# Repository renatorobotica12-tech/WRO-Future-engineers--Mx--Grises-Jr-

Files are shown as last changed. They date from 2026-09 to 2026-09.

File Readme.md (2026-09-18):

<div align="center">

# 🏎️ LOS GRISES JR
## World Robot Olympiad 2026  
### Future Engineers Category
<p align="center">
  
</p>

<br>





<br>






<br>







<br>

---

# 📷 Final Competition Robot

**Insert final robot hero image here**

*(Recommended image: front three-quarter view showing the complete vehicle)*

---

### Official Engineering Repository

Documentation of Team Los Grises Jr's autonomous vehicle developed for:
**World Robot Olympiad 2026 — Future Engineers Category**

---

</div>

# 🚗 Project Overview

Our robot is a fully autonomous four-wheel vehicle designed for the **World Robot Olympiad 2026 Future Engineers competition**.

The objective of this project is to develop a reliable autonomous vehicle capable of navigating the competition environment through a combination of:

- Mechanical engineering.
- Embedded electronics.
- Autonomous control algorithms.
- Sensor processing.
- Software architecture.
- Iterative testing and optimization.

The final platform combines:

| System | Implementation |
|:---|:---|
| Steering | Ackermann steering geometry |
| Drive System | Rear-wheel drive |
| Main Controller | LEGO Mindstorms EV3 Brick, running ev3dev (Debian Linux) |
| Coprocessor | 1 Arduino Nano, multiplexing the five ultrasonic sensors |
| Vision System | HuskyLens AI Camera, through a LEGO UART adapter |
| Distance Measurement | Five ultrasonic sensors |
| Communication | USB serial at 115200 baud, plus LEGO UART for the camera |
| Electronics | Custom-designed PCB |
| Control Algorithm | Proportional wall-centring, with measured filtering and hold-over |
| Control Software | Python, modular package (`Src/ev3dev`) |

---

# ⚡ Quick System Overview

<div align="center">

```mermaid
flowchart TD
    HUSKY["📷 HuskyLens Camera"]
    ULTRA["📡 Ultrasonic Sensors ×5"]
    IMU["🧭 AbsoluteIMU"]

    OFDL["OFDL UART Adapter"]
    PCB["🔌 Custom PCB"]
    NANO["⚙️ Arduino Nano"]

    EV3["🧠 LEGO EV3<br/><i>running ev3dev</i>"]

    STEER["🔄 Steering Motor<br/>port A"]
    DRIVE["🚗 Drive Motor<br/>port B"]

    HUSKY --> OFDL
    ULTRA --> PCB
    PCB --> NANO

    OFDL -->|"LEGO UART · port 3"| EV3
    NANO -->|"USB serial · 115200 baud"| EV3
    IMU -->|"I²C · port 2"| EV3

    EV3 --> STEER
    EV3 --> DRIVE

    classDef sensor fill:#FFE0B2,stroke:#E65100,stroke-width:2px,color:#000
    classDef bridge fill:#B3E5FC,stroke:#01579B,stroke-width:2px,color:#000
    classDef brain  fill:#C8E6C9,stroke:#1B5E20,stroke-width:3px,color:#000
    classDef motor  fill:#F8BBD0,stroke:#880E4F,stroke-width:2px,color:#000

    class HUSKY,ULTRA,IMU sensor
    class OFDL,PCB,NANO bridge
    class EV3 brain
    class STEER,DRIVE motor
```

</div>

The robot uses a distributed architecture where each subsystem performs a specific role:

- The **Arduino Nano** measures the five ultrasonic sensors and streams them over USB.
- The **OFDL adapter** translates the HuskyLens output into the LEGO UART protocol, so the EV3 sees the camera as an ordinary sensor.
- The **EV3 Brick**, running ev3dev, performs navigation decisions and motion control in Python.
- The **Custom PCB** organizes power distribution and signal routing for the sensor array.

**Why USB instead of I²C.** The sensors originally reached the brick over
I²C on a sensor port. The EV3 does not have I²C hardware: it bit-bangs
the protocol in software and it runs at a few kHz. Moving the Nano to USB
at 115200 baud removed that bottleneck and freed a sensor port.

---

# 📑 Table of Contents

- [👥 Team](#-team)
- [🚗 Project Overview](#-project-overview)
- [⚡ Quick System Overview](#-quick-system-overview)
- [⭐ Engineering Highlights](#-engineering-highlights)
- [📊 Robot Specifications](#-robot-specifications)
- [📸 Vehicle Gallery](#-vehicle-gallery)
- [🔩 Components and Hardware](#-components-and-hardware)
- [🛠 Mechanical Design](#-mechanical-design)
- [⚡ Electronics](#-electronics)
- [🔌 Custom PCB](#-custom-pcb)
- [💻 Software Architecture](#-software-architecture)
- [📡 Ultrasonic Sensor Fusion](#-ultrasonic-sensor-fusion)
- [🎮 Wall-Centring Controller](#-wall-centring-controller)
- [👁 Camera Avoidance](#-camera-avoidance)
- [🎯 Automatic Steering Calibration](#-automatic-steering-calibration)
- [🧮 Corner Counting](#-corner-counting)
- [🧠 Engineering Decisions](#-engineering-decisions)
- [📈 Current Performance](#-current-performance)
- [📓 Engineering Journal](#-engineering-journal)
- [📂 Repository Structure](#-repository-structure)
- [🏁 Conclusion](#-conclusion)

---

<div align="center">

### 📚 Jump straight to the detail






</div>

---

# 👥 Team

## 📷 Team Photo

<p align="center">
Team Los Grises Jr
</p>

---

# 👨‍💻 Renato Medina
<p align="center">

</p>

## Team Captain

| Information | Details |
|:---|:---|
| Age | 14 |
| Role | Team Captain and Programmer |
| Main Areas | Software, Integration |

### Responsibilities

- 💻 Software Development
- 🤖 Autonomous Navigation Algorithms
- ⚙️ Mechanical Design
- 🔧 Robot Integration
- 🧠 System Architecture
- 📚 Technical Documentation

---

### About Renato

Renato serves as the **Team Captain** and leads the software architecture, autonomous navigation development, project documentation, and system integration of the robot.

His robotics journey began through the **OnStage TMR program**, where he developed a strong interest in autonomous systems, embedded programming, and engineering design.

Since then, he has focused on combining:

- Software development.
- Electronics.
- Mechanical design.
- Control systems.

to create reliable robotic platforms.

For the WRO 2026 season, his objective is to develop a highly reliable autonomous vehicle while expanding his knowledge of embedded systems, control theory, and robotic engineering.

---

# 👩‍🔧 Paulina

## Mechanical & Electronics Designer

| Information | Details |
|:---|:---|
| Role | Mechanical & Electronics Designer |
| Main Areas | Assembly, Electronics, Testing |

### Responsibilities

- 🔩 Mechanical Assembly
- ⚡ Electronics Integration
- 🔌 PCB Installation
- 🧪 Robot Testing
- 📐 Structural Optimization
- 🛠 Cable Organization

---

### About Paulina

Paulina is responsible for the robot's mechanical construction and electronic integration.

Her work focuses on:

- Structural assembly.
- Sensor installation.
- PCB integration.
- Mechanical validation.
- Hardware reliability.

Her contributions have been fundamental in transforming the initial prototype into a competition-ready autonomous vehicle with improved stability and maintainability.

📷 **Insert Paulina working on assembly image here**

---

# 🤝 Team Responsibilities

| Area | Renato | Paulina |
|:---|:---:|:---:|
| Mechanical Design | ✅ | ✅ |
| Robot Assembly | ✅ | ✅ |
| Electronics Integration | | ✅ |
| PCB Installation | ✅ | ✅ |
| Software Development | ✅ | |
| EV3 Programming | ✅ | |
| Arduino Programming | ✅ | |
| Documentation | ✅ | ✅ |
| Testing & Validation | ✅ | ✅ |

---

# ⭐ Engineering Philosophy

> [!IMPORTANT]
>
> The development of Los Grises Jr is based on continuous engineering improvement.
>
> Every subsystem has been tested, analyzed, modified, and optimized with three main objectives:
>
> - Increase reliability.
> - Improve repeatability.
> - Simplify maintenance.

---

# ⭐ Engineering Highlights

The current robot incorporates multiple engineering improvements developed specifically for the **WRO Future Engineers Challenge**.

| Feature | Implementation |
|:---|:---|
| Steering System | Ackermann steering geometry |
| Drive System | Rear-wheel drive |
| Sensors | Five ultrasonic sensors, with dropout filtering |
| Vision | HuskyLens AI camera, with hold-over and nearest-block selection |
| Coprocessor | 1 Arduino Nano streaming over USB |
| Electronics | Custom PCB |
| Communication | USB serial at 115200 baud |
| Steering Calibration | Automatic, measured against the mechanical stops |
| Control | Proportional, with every gain measured and recorded |
| Drive Control | Closed loop on the encoder, not raw power |
| Software | Modular Python package |
| Sensor Mounting | Custom 3D printed supports |
| Mechanical Design | Optimized weight distribution |

---

<div align="center">

# 📊 Robot Specifications

<div align="center">

| Specification | Value |
|:---|:---|
| Competition | WRO Future Engineers 2026 |
| Robot Type | Autonomous Vehicle |
| Dimensions | 24 × 23 × 18 cm |
| **Mass** | **861 g** |
| Maximum Allowed Size | 30 × 30 × 30 cm |
| Steering System | Ackermann Steering |
| Drive System | Rear-Wheel Drive |
| Chassis | LEGO Mindstorms EV3 |
| Main Controller | LEGO EV3 Brick running ev3dev |
| Coprocessor | Arduino Nano |
| Vision System | HuskyLens AI Camera |
| Distance Sensors | Five Ultrasonic Sensors |
| Gyroscope | mindsensors AbsoluteIMU |
| Communication Protocol | USB serial, 115200 baud |
| Custom Electronics | Custom PCB |
| Sensor Supports | 3D Printed |
| Programming Languages | Python (EV3) and Arduino C++ (Nano) |
| Control Loop Rate | ~30 Hz measured on track |

</div>

---

# 📸 Vehicle Gallery

The following images show the final competition vehicle from different perspectives.

These photographs demonstrate:

- Mechanical construction.
- Sensor placement.
- Electronics integration.
- Cable organization.
- Overall vehicle design.

<div align="center">

| Front View | Top View | Right Side |
|:---:|:---:|:---:|
|  |  |  |

| Left Side | Rear View | Bottom View |
|:---:|:---:|:---:|
|  |  |  |

</div>

> [!NOTE]
>
> A demostration video will be added after the final validation tests are completed.

---

# 🔩 Components and Hardware

The robot combines LEGO components with custom embedded electronics to create a modular and reliable autonomous platform.

Each component was selected according to:

- Reliability.
- Compatibility.
- Mechanical integration.
- Software requirements.
- Long-term maintainability.

| Component | Quantity | Function | Status |
|:---|:---:|:---|:---:|
| LEGO EV3 Brick | 1 | Main controller, runs ev3dev | ✅ |
| EV3 Medium Motor | 1 | Rear-wheel traction — **port B** | ✅ |
| EV3 Medium Motor | 1 | Ackermann steering — **port A** | ✅ |
| Ultrasonic Sensors | 5 | Distance measurement | ✅ |
| Arduino Nano | 1 | Sensor acquisition, USB serial | ✅ |
| HuskyLens AI Camera | 1 | Vision processing — **port 3** | ✅ |
| mindsensors AbsoluteIMU | 1 | Heading and corner counting — **port 2** | ✅ |
| OFDL UART Adapter | 1 | Presents the camera as a LEGO sensor | ✅ |
| Custom PCB | 1 | Power and signal distribution | ✅ |
| LEGO Wheels | 4 | Vehicle mobility | ✅ |
| 3D Printed Supports | Multiple | Sensor mounting | ✅ |

> [!NOTE]
> The complete port assignment, verified on the robot, is in
> [`mechanic/List of ports and components.md`](mechanic/List%20of%20ports%20and%20components.md).

---

# 🛠 Mechanical Design

## Design Evolution

The mechanical structure of the robot was developed through multiple iterations focused on:

- Structural rigidity.
- Weight distribution.
- Driving stability.
- Maintenance accessibility.
- Competition compliance.

Rather than modifying only a single prototype, the robot evolved progressively through testing and engineering improvements.

Every redesign addressed specific limitations discovered during previous experiments.

The result is a compact autonomous vehicle designed for reliability and repeatability.

---

## 📷 Mechanical Design Overview

<div align="center">

**Insert chassis evolution image here**

</div>

---

# 📏 Final Dimensions

| Measurement | Value |
|:---|:---:|
| Length | 24 cm |
| Width | 23 cm |
| Height | 18 cm |
| **Mass** | **861 g** |

The final design remains within the official WRO Future Engineers national competition limit of:

```
30 × 30 × 30 cm
```

### Why the mass is worth recording

861 g is not just a specification line. Combined with the drive motor's
running torque it sets the vehicle's dynamic limits:

| Derived quantity | Value |
|:---|---:|
| Weight | 8.45 N |
| Tractive force available | ≈ 2.86 N |
| Maximum acceleration | ≈ 3.32 m/s² |
| Friction coefficient required not to slip | μ ≥ 0.34 |

The full derivation is in
[**docs/Control_Model.md § 5**](docs/Control_Model.md).

The available internal space allows integration of:

- EV3 electronics.
- Arduino coprocessor.
- Custom PCB.
- Sensor wiring.
- Steering mechanism.

---

# ⚖️ Weight Distribution

Achieving a balanced center of gravity was one of the main mechanical objectives.

Instead of concentrating all components in one area, the mass was intentionally distributed throughout the chassis.

## Main Design Decisions

| Component | Position |
|:---|:---|
| EV3 Brick | Rear section |
| Drive Motor | Center area |
| Steering Motor | Above steering mechanism |
| Custom PCB | Near sensor assembly |
| Arduino Nano | Adjacent to PCB |

This configuration improves:

- Acceleration stability.
- Braking behavior.
- Cornering performance.
- Mechanical reliability.

---

# 🔄 Ackermann Steering System

The robot uses an Ackermann-inspired steering mechanism powered by an EV3 Medium Motor.

Unlike differential steering systems, Ackermann geometry allows the vehicle to follow more realistic turning trajectories by reducing tire slip.

## Steering Control Method

The steering motor is controlled using encoder positions instead of continuous rotation.

This provides:

✅ Repeatable steering angles  
✅ Faster response  
✅ Automatic steering centering  
✅ Reduced positioning error  

---

## Steering Protection

The software limits the maximum steering angle to prevent:

- Mechanical overtravel.
- Transmission stress.
- Unnecessary motor load.

---

# 🚗 Rear-Wheel Drive

The vehicle uses a rear-wheel-drive configuration powered by an EV3 Medium Motor.

This architecture was selected because it provides several advantages:

| Advantage | Result |
|:---|:---|
| Better weight transfer | Improved acceleration |
| Independent steering system | Less interference |
| Simpler drivetrain | Increased reliability |
| Easier maintenance | Faster repairs |

Separating propulsion and steering makes vehicle behavior more predictable during autonomous navigation.

---

# 📡 Sensor Mounts

All ultrasonic sensors are installed using custom-designed 3D printed brackets.

<div align="center">

📷 **Insert sensor mount image here**

</div>

The supports were designed to:

- Maintain precise alignment.
- Reduce vibration.
- Improve rigidity.
- Simplify installation.
- Guarantee repeatable sensor positioning.

Compared with direct LEGO mounting, the printed supports significantly improve measurement consistency.

---

# ⚡ Electronics

The robot combines LEGO electronics with custom embedded hardware to create a modular electrical architecture.

The system is divided into two main processing units:

| Controller | Responsibility |
|:---|:---|
| LEGO EV3 Brick | Navigation, decision making, motor control |
| Arduino Nano | Ultrasonic acquisition and serial streaming |
| OFDL adapter | Camera protocol translation (not programmed by the team) |

This distributed architecture provides:

- Reduced wiring complexity.
- Lower EV3 port usage.
- Easier debugging.
- Better scalability.

---

# 🔌 Electronic Architecture

<div align="center">

```mermaid
flowchart LR
    subgraph ACQ ["📡 Acquisition"]
        direction TB
        U1["Ultrasonic 1<br/>left 90°"]
        U2["Ultrasonic 2<br/>left 25°"]
        U3["Ultrasonic 3<br/>front"]
        U4["Ultrasonic 4<br/>right 25°"]
        U5["Ultrasonic 5<br/>right 90°"]
    end

    subgraph ROUTE ["🔌 Routing"]
        PCB["Custom PCB"]
        NANO["Arduino Nano<br/><i>trig / echo · 9 ms apart</i>"]
    end

    subgraph DEC ["🧠 Decision"]
        EV3["LEGO EV3<br/><i>ev3dev · Python</i>"]
    end

    subgraph ACT ["⚙️ Actuation"]
        MA["Steering · port A"]
        MB["Drive · port B"]
        MD["Nano power · port D"]
    end

    U1 & U2 & U3 & U4 & U5 --> PCB
    PCB --> NANO
    NANO -->|"USB · 115200 baud<br/>≈110 lines/s"| EV3
    EV3 --> MA
    EV3 --> MB
    EV3 -.->|"dc-motor · 100% duty"| MD
    MD -.->|"power"| NANO

    classDef s fill:#FFE0B2,stroke:#E65100,color:#000
    classDef r fill:#B3E5FC,stroke:#01579B,color:#000
    classDef d fill:#C8E6C9,stroke:#1B5E20,stroke-width:3px,color:#000
    classDef a fill:#F8BBD0,stroke:#880E4F,color:#000

    class U1,U2,U3,U4,U5 s
    class PCB,NANO r
    class EV3 d
    class MA,MB,MD a
```

</div>

The architecture separates:

- Sensor acquisition.
- Data communication.
- Decision making.
- Vehicle control.

This modular approach allows each subsystem to be tested independently.

---

# 🔌 Custom PCB

<p align="center">
Custom interface PCB built around the Arduino Nano
</p>

One of the most important improvements during development was the creation of a custom Printed Circuit Board.

During early testing, sensors were connected individually using loose wiring.

Although functional, this approach caused:

❌ Cable clutter  
❌ Difficult maintenance  
❌ Loose connections  
❌ Limited organization  

To solve these problems, a dedicated PCB was designed specifically for this robot.

---

## PCB Functions

The custom PCB provides:

| Function | Purpose |
|:---|:---|
| Power distribution | Organized electrical supply |
| Signal routing | Cleaner connections |
| Sensor interfaces | Easy sensor replacement |
| Arduino interface | Simplified communication |
| Cable management | Improved organization |

---

## PCB Advantages

Compared with individual wiring, the PCB provides:

✅ Cleaner internal organization  
✅ Faster assembly  
✅ Easier troubleshooting  
✅ Higher mechanical reliability  
✅ Reduced accidental disconnections  
✅ Better future expansion capability  

---

<div align="center">

Software Architecture • Sensor Fusion • Wall Centring • Camera Avoidance • Steering Calibration • Corner Counting • Engineering Decisions
</div>
# 💻 Software Architecture

The control software runs in Python on the EV3 brick under ev3dev. It is
organised as a package, `Src/ev3dev/wro`, where each module owns one part
of the robot and nothing else:

| Module | Responsibility |
|:---|:---|
| `config.py` | Every tunable value, and how each one was measured |
| `ultrasonics.py` | Reading the Nano, and filtering sensor dropouts |
| `husky.py` | The camera, and choosing which block to avoid |
| `imu.py` | Heading integration and corner counting |
| `robot.py` | Drive train and steering |
| `power.py` | Powering the Nano from a motor port |
| `ports.py`, `i2c.py`, `util.py` | Low-level helpers |

Two programs use that package, one per challenge:

| Program | Challenge |
|:---|:---|
| `open_ard.py` | Open challenge — three laps, walls only |
| `obs_ard.py` | Obstacle challenge — three laps, avoiding coloured pillars |

A third, `check_hw.py`, never races. It is a diagnostics tool with
thirteen commands, and it exists because several values cannot be decided
at a desk: which frame index belongs to which sensor, the gyroscope scale
and sign, and how far the steering actually travels. Guessing those wrong
produces failures that look like software bugs.

This organization improves:

✅ Code readability
✅ Debugging efficiency
✅ Testing capability
✅ Repeatability
✅ System reliability
✅ Ease of maintenance

## 🧩 Software Execution Flow

Every start-up runs the same three-stage sequence before the robot is
allowed to move:

```mermaid
flowchart TD
    A(["🏁 START"]) --> B["🔌 Power the Nano from port D<br/>open the serial link"]
    B --> C["🎯 Find both steering stops<br/>midpoint becomes centre"]
    C --> D["🧭 Calibrate gyroscope zero<br/><i>robot must be still</i>"]
    D --> E["📋 Print the values actually in use"]
    E --> F{{"⏸️ Wait for centre button"}}

    F --> G["📥 Read camera · ultrasonics · gyroscope"]
    G --> H{"Turn ≥ 87°<br/>and ≥ 1.5 s since<br/>the last corner?"}

    H -->|yes| I["➕ Count corner"]
    H -->|no| J
    I --> J{"12 corners<br/>reached?"}

    J -->|yes| K["🛬 Run on 500 ms<br/>still following walls"]
    K --> L(["🛑 STOP"])

    J -->|no| M["🚗 Drive at configured speed"]
    M --> N{"Camera sees<br/>a block?"}

    N -->|yes| O["👁 Steer around it<br/>by its colour"]
    N -->|no| P["📏 Centre between the walls"]

    O --> G
    P --> G

    classDef setup  fill:#E1BEE7,stroke:#4A148C,stroke-width:2px,color:#000
    classDef sense  fill:#FFE0B2,stroke:#E65100,stroke-width:2px,color:#000
    classDef choice fill:#FFF9C4,stroke:#F57F17,stroke-width:2px,color:#000
    classDef act    fill:#C8E6C9,stroke:#1B5E20,stroke-width:2px,color:#000
    classDef stop   fill:#FFCDD2,stroke:#B71C1C,stroke-width:3px,color:#000

    class B,C,D,E setup
    class G sense
    class H,J,N,F choice
    class I,M,O,P act
    class K,L stop
```

> [!NOTE]
> The order inside the loop is deliberate. The drive motor is given the
> speed computed on the **previous** iteration, so a corner detected on
> this iteration stops the robot without one last burst of throttle.

---
    
# 📡 Ultrasonic Sensor Fusion

The robot uses multiple ultrasonic sensors to determine its position relative to the surrounding walls.

Instead of relying on a single sensor, the readings are combined into two groups. Each group represents one side of the robot.

The lateral error is calculated as the difference between both groups:

```
left  = left_90  + left_25
right = right_25 + right_90

ERROR = -(left - right)
```

**The negation matters.** If the robot drifts towards the left wall, the
left readings fall, the error comes out **positive**, and a positive
steering command turns **right** — away from the wall. That sign is what
makes the whole chain close.

Because each side sums two sensors, a sideways drift moves all four at
once: two get closer while two get further away. The error therefore
grows about four times faster than the actual displacement, which is why
the gain looks small compared with the numbers involved.

## Handling dropped readings

When an ultrasonic sensor receives no echo, the firmware sends **125**
and clears that sensor's validity bit. **125 is a sentinel, not a
distance.** Added straight into the error, one dropout looks like an 80 cm
jump and slams the steering to full lock.

Measured with `check_hw.py lazo`: the error went from **+5 to −82 and
back to +31 in under a second, with the robot standing still.**

The fix is a three-state filter, applied per sensor:

| Situation | What is used |
|:---|:---|
| Valid reading | The reading itself, and it is remembered |
| Short dropout | The last good reading, held for 0.5 s |
| Long dropout | The maximum useful distance — there really is no wall |

A rolling median of three then removes isolated spikes that arrive with
their validity bit set.

Each run prints how many substitutions each sensor needed. That number is
a hardware health check: **a sensor substituting a quarter of the time is
a fault no amount of gain tuning compensates for.** Finding exactly that
is how we caught a dead sensor during testing.

# 🎮 Wall-Centring Controller

Steering correction is **proportional**:

```
angle = VOLANTE_KP × ERROR      clamped to ±VOLANTE_LIMITE
```

One gain, no derivative and no integral term. That is a deliberate
choice, not an omission — and the reasoning is recorded in
[`Logs_Tuning.md`](docs/Logs_Tuning.md), where the integral term was
found to saturate the steering actuator on track imperfections.

What makes this controller reliable is not the form of the equation but
knowing what the gain *means*:

| Gain | Saturates at error | Roughly |
|:---:|:---:|:---|
| 10 | 5 | 1 cm off centre — effectively on/off |
| 3 | 16.9 | 4 cm off centre |
| 1.5 | 33.7 | 8 cm off centre |

`config.py` derives that saturation point automatically, so the meaning
of the gain is visible next to the gain itself rather than having to be
recomputed by hand.

**One tuning lesson worth recording:** we once raised the gain as high as
10 chasing a robot that would not respond. The real cause was a dead
ultrasonic sensor pinning the error at a constant +62. With the sensor
repaired the true operating error turned out to be 5 to 9, and a gain of
10 saturated the steering permanently. **The gain was compensating for a
broken sensor.**

# ⚡ Speed Control

The two challenges use independent speeds, because they are solving
different problems:

| Challenge | Speed | Why |
|:---|:---:|:---|
| Open | 70 | Only has to stay centred; can afford to be quick |
| Obstacle | 40 | The camera must see a block, choose a side and complete the detour before reaching it |

Speed is commanded as a **percentage of the motor's maximum speed**, with
the EV3 regulating on the encoder. If a wheel is slowed by a track
imperfection, the controller raises power on its own until the commanded
speed is recovered. Commanding raw duty cycle instead is open loop: the
robot simply bogs down. We changed to closed loop after exactly that kept
happening on track.

# 👁 Camera Avoidance

In the obstacle challenge the camera takes over the steering whenever it
sees a coloured pillar. The rule is a proportional controller on the
block's **position in the image**:

```
error = X - target
angle = map(error, -160..+160, -limit..+limit)
```

`target` is where the block should end up in the frame, and it is the
knob that sets how wide the detour is:

| Colour | ID | Target | Result |
|:---|:---:|:---:|:---|
| Red | 1 | −150 | Block ends up left in frame → robot passes on the **right** |
| Green | 2 | +150 | Block ends up right in frame → robot passes on the **left** |

This reads backwards the first time. It is because the camera looks where
the robot is *going*, not at the block: to leave a pillar on your left,
you must be pointing to the right of it.

The target must stay inside ±160, the edge of the image. **A target
outside that range is a position the block can never reach**, so the
error never crosses zero and the steering never straightens out while the
block is in view.

## Three problems the camera created

**The adapter's documented data layout is wrong.** Its README lists six
values as `State, ID, X, Y, W, H`. The adapter actually returns **eight**
values in a different order: `X, Y, W, H, ID, State`. We found this by
watching index 5 alternate between 1 and 7 — exactly the codes for
"object detected" and "sees none" — with every other value dropping to
zero when it read 7.

**Reading it naively cost 49 ms.** Eight separate reads took long enough
to hold the whole control loop at 20 Hz. Reading the raw 32-byte block in
one atomic call takes 5 ms, and has the side benefit that data from two
frames can never be mixed.

**The camera flickers, and the adapter switches blocks.** A one-frame
dropout used to hand control back to wall following, which at that
instant saw a large error and went to full lock: measured at **+1.9° to
+50.6° and back inside 300 ms, with the block in view the whole time.**
And with two pillars visible, the adapter alternates which one it
reports, producing commands for opposite sides on consecutive loops.

Both are solved, but not the same way:

| Problem | Solution | Why this one |
|:---|:---|:---|
| Flicker | Hold the last good command for 0.15 s | Covers the 1–3 loop dropouts measured |
| Block switching | Only yield control to a **wider** block | Wider means closer; the closest pillar is the urgent one |

We first tried stretching the hold window to fix both. It did not work —
the retention rate tripled to 31 % while the switching continued
unchanged, because the adapter stays on the other block for longer than
any reasonable window. **The longer window only made the robot act on
stale images.** Width is the right criterion, and it is the only
proximity information the adapter provides.

# 🎯 Automatic Steering Calibration

At every start-up the robot pushes the steering against both mechanical
stops and takes the midpoint as zero. That is reliable even if the robot
was stored with the wheels turned.

Two things were learned building this:

**The stop is not where the motor stops moving.** At 40 % duty the
steering advances 28 degrees and jams halfway; it takes 100 % to actually
reach the stop. An earlier version accepted the first stall as the stop,
measured 26 degrees of travel instead of 111, and put the centre almost
50 degrees off. The search now walks the full power ladder every time.

**Forced travel and free travel are different numbers, and the
difference is not steering.** Measured on this robot: 153 degrees pushing
at full power, 119 at minimum power. Those 34 degrees are the mechanism
flexing against the stops. The steering limit is derived from the **free**
travel with a 15 % margin; taking it from the forced travel would make
the steering fight the stops on every correction.

# 🧮 Corner Counting

Laps are counted by integrating the gyroscope: 87 degrees of accumulated
turn is a corner, twelve corners is three laps.

That works in the open challenge. In the obstacle challenge it broke,
and the reason is worth recording: **while avoiding a block the steering
goes to full lock and the robot genuinely turns.** The gyroscope cannot
tell that from a track corner, accumulates its 87 degrees, and counts a
corner that does not exist.

Measured on track: **two corners 1.1 seconds apart, where the real ones
were arriving every 6.** In a race that is fatal — each false corner
brings the target of twelve closer, and the robot brakes mid-track
believing it has finished.

Corners arriving closer together than 1.5 seconds are now discarded. The
angle is still reset, because that turn physically happened and carrying
it forward would trigger the next corner early. Each run reports how many
false corners were rejected.

---

# 🧠 Engineering Decisions

Every major engineering decision was based on testing, analysis, and continuous improvement.

| Decision | Reason | Benefit |
|:---|:---|:---|
| Ackermann Steering | More realistic vehicle geometry | Smoother turns |
| Rear-Wheel Drive | Separates propulsion and steering | Better reliability |
| Encoder Steering | Absolute position control | Repeatable angles |
| Five Ultrasonic Sensors | Increased environmental awareness | Better perception |
| Arduino Nano Coprocessor | Dedicated sensor processing | Reduced EV3 workload |
| USB instead of I²C | The EV3's sensor-port I²C is bit-banged in software at a few kHz | Removed the bottleneck, freed a port |
| Custom PCB | Organized electronics | Improved maintenance |
| 3D Printed Mounts | Fixed sensor position | Better measurements |
| Python on ev3dev | Control maths written literally instead of approximated with blocks | Every gain carries its reasoning |
| Modular Software | Independent modules | Easier development |
| Proportional control | The integral term saturated the actuator on track imperfections | Predictable, tunable behaviour |
| Closed-loop drive | Raw duty cycle stalls against track imperfections | Speed is held, not just requested |
| Sensor dropout filter | A missing echo is a sentinel, not a distance | One dropout no longer causes full lock |
| Camera hold-over | One lost frame is not a lost block | No steering jerk mid-avoidance |
| Nearest-block selection | The adapter switches between visible pillars | No contradictory commands |
| False corner rejection | An avoidance turn looks identical to a corner | Lap count survives the obstacle run |

---

# 📈 Current Performance

Current testing demonstrates that the robot provides reliable autonomous behavior.

Achievements:

✅ Stable lane-centering  
✅ Smooth steering corrections  
✅ Automatic steering calibration  
✅ Consistent multi-run performance  
✅ Arduino-EV3 link with **zero bad frames** across full runs  
✅ Control loop sustained at **~30 Hz** on track  
✅ Improved electrical reliability after PCB integration  
✅ Strong mechanical structure for repeated testing  

Every run reports its own diagnostics: loop rate, corners counted, false
corners rejected, bad frames from the Nano, and per-sensor substitution
counts. Those numbers are how hardware faults get caught before they are
mistaken for tuning problems.

The current platform provides a reliable foundation for completing future competition objectives.

---

# 📓 Engineering Journal

The complete engineering process is documented in a dedicated engineering journal.

The journal includes:

- Mechanical iterations.
- Hardware modifications.
- Software development.
- Testing procedures.
- Engineering decisions.
- Performance analysis.

| Document | What it covers |
|:---|:---|
| 📓 [**Engineering Journal**](docs/Engineering%20Journal.md) | The development story, entry by entry — including the failures |
| 📊 [**Tuning Log**](docs/Logs_Tuning.md) | Controller tuning, iteration by iteration, with observed behaviour |
| 🧮 [**Mathematical Control Model**](docs/Control_Model.md) | Every equation and constant, derived and cross-checked against measurement |
| 🔧 [**Software Guide**](Src/ev3dev/README.md) | Installation, the calibration sequence, and how to run each challenge |
| 🔌 [**Ports and Components**](mechanic/List%20of%20ports%20and%20components.md) | The complete wiring, verified on the robot |

---

# 📂 Repository Structure

```text
.
├── Src
│   ├── ev3dev                    Control software, Python on the EV3
│   │   ├── check_hw.py           Diagnostics, 13 commands
│   │   ├── open_ard.py           Open challenge
│   │   ├── obs_ard.py            Obstacle challenge
│   │   └── wro/                  The library the programs import
│   │       ├── config.py         Every tunable value, and how it was measured
│   │       ├── robot.py          Drive train and steering
│   │       ├── imu.py            Gyroscope and corner counting
│   │       ├── ultrasonics.py    The Nano, and dropout filtering
│   │       ├── husky.py          Camera and block selection
│   │       ├── power.py          Powering the Nano from a motor port
│   │       ├── ports.py          Sensor port modes
│   │       ├── i2c.py            Raw I2C access
│   │       └── util.py           Numeric helpers
│   │
│   └── arduino_nano              Firmware for the ultrasonic hub
│       ├── ultrasonic_hub_serial.ino    in use — USB, 115200 baud
│       ├── ultrasonic_hub_packet.ino    I2C fallback, framed
│       └── ultrasonic_hub.ino           original, one byte per request
│
├── docs
│   ├── Engineering Journal.md
│   ├── Logs_Tuning.md            Controller tuning, iteration by iteration
│   ├── Control_Model.md          Every equation and constant, derived
│   ├── OPEN_ARD_EQUIVALENCIA.md
│   ├── PROTOCOLO_I2C_MULTIPLEXOR.md     The Nano's I2C frame format
│   └── BLOQUE_GIRO_ABSOLUTEIMU_EV3.md   Gyroscope integration
│
├── Electronics                   PCB design notes
├── mechanic                      Diagrams, port list, 3D printable parts
├── Photos                        Team and vehicle photographs
├── Videos                        Demonstration footage
│
├── LICENSE
└── Readme.md
```

> [!NOTE]
> `Src/ev3dev/wro` is a library. The programs import it, but nothing
> inside it is meant to be run on its own. Start with
> [`Src/ev3dev/README.md`](Src/ev3dev/README.md), which covers
> installation, the calibration sequence and how to run each challenge.

---

# 📅 Development Timeline

| Date | Milestone |
|:---|:---|
| 4 Jul 2026 | Initial PD controller prototype |
| 8 Jul 2026 | PCB manufacturing |
| 10 Jul 2026 | PCB assembly and testing |
| 13 Jul 2026 | First control software beta |
| 21 Jul 2026 | I²C communication completed |
| 27 Jul 2026 | Sensor multiplexer integrated, 3D printed mounts fitted |
| 28 Jul 2026 | Final robot assembly |
| 24 Aug 2026 | Faulty Arduino Nano diagnosed after four weeks |
| 28 Aug 2026 | Open challenge completed on track |
| 6 Sep 2026 | IMU integrated for corner counting |
| 12 Sep 2026 | Migration to Python on ev3dev; Nano moved from I²C to USB |
| 13 Sep 2026 | Steering travel measured; steering command defect found and fixed |
| 13 Sep 2026 | Dead ultrasonic sensor diagnosed and repaired |
| 14 Sep 2026 | Camera hold-over, nearest-block selection, false corner rejection |

---

# 🙏 Acknowledgements

We would like to thank our mentors, teachers, and everyone who supported the development of this project throughout the WRO 2026 season.

Their guidance, technical advice, and encouragement were essential in transforming an initial concept into a functional autonomous vehicle.

---

# 🏁 Conclusion

The current version of the **Los Grises Jr autonomous vehicle** represents the result of an iterative engineering process involving:

- Mechanical design.
- Electronics development.
- Embedded programming.
- Control theory.
- Autonomous navigation.

Compared with the earliest prototypes, the final platform incorporates:

✅ Custom-designed PCB  
✅ Arduino Nano coprocessor streaming over USB  
✅ Ackermann steering system  
✅ Automatic steering calibration, measured against the mechanical stops  
✅ Proportional wall-centring with measured, documented gains  
✅ Camera avoidance with hold-over and nearest-block selection  
✅ Modular Python software architecture  
✅ Improved mechanical reliability  

The project continues evolving toward the completion of the remaining WRO challenges while maintaining the engineering principles that guided the entire development process:

> **Reliability, repeatability, and continuous improvement.**

---

<div align="center">

# 🏎️ Team Los Grises Jr

## World Robot Olympiad 2026  
## Future Engineers Category

</div>

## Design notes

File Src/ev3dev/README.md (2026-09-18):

# Programa de Arath portado a ev3dev

Version en Python de los dos programas Arduino de Arath, corriendo sobre
el ladrillo EV3. No reemplaza a los programas EV3-G del proyecto `ev3/`;
es un camino paralelo.

## Por que ev3dev y no EV3-G

El programa de Arath es codigo, no bloques. En EV3-G hubo que aproximarlo
(ver `documentos/OPEN_ARD_EQUIVALENCIA.md`): el `map` y el factor 0.9 se
cambiaron por el bloque `PID_R_20`, la zona muerta se omitio y el conteo
de esquinas se rehizo con bloques. En ev3dev cada una de esas piezas se
escribe tal cual, y ademas se puede leer el Nano por USB en vez de por el
I2C lento de los puertos de sensores.

## Cableado

Confirmado en el robot con `check_hw.py puertos`:

| Puerto | Dispositivo | Como lo ve ev3dev |
|---|---|---|
| Sensor 2 | mindsensors AbsoluteIMU | `ms-absolute-imu` en `ev3-ports:in2:i2c17` |
| Sensor 3 | HuskyLens por el adaptador OFDL | `ev3-uart-84` |
| USB del ladrillo | Arduino Nano, cinco ultrasonicos | `/dev/ttyUSB0` |
| Motor A | volante | `lego-ev3-m-motor` |
| Motor B | traccion | `lego-ev3-m-motor` |

Los puertos de sensores 1 y 4 y los de motores C y D quedan libres.

Dos cosas no coinciden con `documentos/OPEN_ARD_EQUIVALENCIA.md`, que
describia el montaje de EV3-G:

- la traccion **no** es un motor grande en D, sino un **mediano en B**;
- el volante **no** esta en B sino en **A**.

Por eso `robot.py` usa la clase generica `Motor` y no `LargeMotor` ni
`MediumMotor`: esas dos filtran por `driver_name` y `LargeMotor` revienta
con un motor mediano. Nada de lo que hace ese archivo depende del tamano
del motor.

### El Nano por USB

Se le carga el firmware nuevo
[`arduino_nano/ultrasonic_hub_serial`](../arduino_nano/ultrasonic_hub_serial/ultrasonic_hub_serial.ino)
y se conecta con su propio cable USB al puerto USB del ladrillo. El
cableado de los ultrasonicos no cambia: mismos pines trig y echo.

Manda lineas ASCII a 115200 baudios:

```
U d1 d2 d3 d4 d5 mascara trama checksum
```

Una linea despues de **cada** sensor, no de cada barrido, para que el EV3
siempre tenga el dato mas fresco. Son unas 110 lineas por segundo. El EV3
descarta las viejas y se queda con la ultima completa.

Por que asi y no por I2C: el I2C de los puertos de sensores del EV3 no es
hardware, lo genera por software y va a pocos kHz. Ademas libera un
puerto de sensores y deja los pines A4 y A5 del Nano libres.

### La HuskyLens

El adaptador de OFDL Robotics no expone la camara por I2C: lleva un
Arduino Pro Mini que traduce los datos al **protocolo LEGO UART**. Para
el EV3 es un sensor LEGO cualquiera, asi que **ev3dev lo detecta solo**.
No hay que tocar el modo del puerto ni cargar drivers, a diferencia del
Nano en I2C.

**Ojo con el orden de los valores: el README del adaptador no coincide
con lo que entrega de verdad.** Ahi dice seis valores en el orden
`State, ID, X, Y, W, H`. Medido en el robot son **ocho** valores s32 y el
orden es otro:

```
0 X   1 Y   2 W   3 H   4 ID   5 State   6 y 7 siempre 0
```

Se confirma mirando el indice 5: alterna entre 1 y 7, que son justo los
codigos de "objeto detectado" y "no ve ninguno", y cuando vale 7 todos
los demas se van a cero.

`husky.py` lee `bin_data` en vez de ocho `value(i)`: es una sola lectura
atomica de 32 bytes, asi que no mezcla datos de dos fotogramas, y tarda
5 ms en vez de 49 ms. A 49 ms la camara sola dejaria el lazo en 20 Hz.

Codigos de State del adaptador:

| Codigo | Significado |
|---:|---|
| 9 | adaptador conectado pero HuskyLens no |
| 8 | conectada, sin objetos aprendidos |
| 7 | conectada y con objetos aprendidos, no ve ninguno |
| 1 | hay objeto detectado |
| 0 | puerto desconectado o perdida de datos |

`obs_ard.py` imprime este estado al arrancar, antes de calibrar.

## Estructura

Solo se corren tres archivos. La carpeta `wro/` es una biblioteca: los
programas la importan, pero **no se ejecuta nada de adentro**, igual que
los bloques `ARD` o `PID_R_20` de EV3-G existen para que los programas
los llamen y no para correrlos sueltos.

```
ev3dev/
  check_hw.py        SE CORRE  diagnostico; primero que nada
  open_ard.py        SE CORRE  prueba abierta, tres vueltas
  obs_ard.py         SE CORRE  prueba de obstaculos

  wro/               no se corre nada de aqui
    config.py        se EDITA: puertos, cableado y ganancias
    robot.py         traccion y volante
    imu.py           AbsoluteIMU e integracion del angulo
    ultrasonics.py   Nano, por USB o por I2C
    husky.py         HuskyLens por el adaptador OFDL
    ports.py         modos I2C de los puertos de sensores
    i2c.py           acceso I2C crudo
    util.py          map y constrain de Arduino
```

De esos tres, `check_hw.py` no mueve el robot salvo en el comando
`volante`: solo lee sensores e imprime. Es el que se usa para llenar
`wro/config.py`. Los otros dos son las carreras.

## Instalacion

En el ladrillo, con ev3dev ya arrancado:

```bash
sudo pip3 install pyserial smbus2
```

`smbus2` solo hace falta si dejan el Nano en I2C (`ARD_BACKEND = 'i2c'`).

Copiar la carpeta al ladrillo conservando el nombre, para que quede
`~/ev3dev/check_hw.py` y `~/ev3dev/wro/config.py`:

```bash
scp -r ev3dev robot@ev3dev.local:~/ev3dev
```

Dar permiso de ejecucion:

```bash
chmod +x ~/ev3dev/*.py
```

Todos los comandos de aqui en adelante se corren parados en esa carpeta:

```bash
cd ~/ev3dev
```

Los archivos deben conservar finales de linea LF. Si al correrlos sale
`bad interpreter`, es eso.

Si al abrir el puerto serie sale permiso denegado:

```bash
sudo usermod -a -G dialout robot
```

## Antes de la primera corrida

Hay varias cosas que solo se pueden medir en el robot. `check_hw.py` las
resuelve una por una.

```bash
python3 check_hw.py puertos
```

Lista puertos, drivers, buses I2C, puertos serie y motores. Confirma que
el AbsoluteIMU aparece como `ms-absolute-imu`, que la HuskyLens aparece
en el puerto 3 como sensor UART y que existe `/dev/ttyUSB0`.

```bash
python3 check_hw.py serie
```

Lineas crudas del Nano. Separa un problema de cable de uno de formato.

```bash
python3 check_hw.py ultra
```

Trama ya interpretada, en vivo.

```bash
python3 check_hw.py mapear
```

Averigua solo que indice es cada ultrasonico: toma una linea base con
todo despejado y despues pide acercar la mano a uno por uno. Al final
imprime `IDX_IZQ`, `IDX_FRONTAL` e `IDX_DER` listos para pegar. La mano
va a unos 10 cm, no pegada al sensor: demasiado cerca no hay eco y el
firmware devuelve 125, que confunde la medicion.

```bash
python3 check_hw.py husky
```

Imprime el driver, la lista de modos y los seis valores en vivo. Resuelve
tres cosas: que poner en `HUSKY_MODO` (ev3dev llama a los modos `MODE0`,
`MODE1`... porque no conoce este sensor), en que rango vienen X e Y para
ajustar `HUSKY_CENTRO_X` y `HUSKY_CENTRO_Y`, y que ID le toca a cada
color para `HUSKY_ID_A` y `HUSKY_ID_B`. Pongan un bloque de cada color
delante de la camara y anoten el ID.

```bash
python3 check_hw.py escala
```

Calcula `IMU_ESCALA`: integra la lectura cruda mientras usted gira el
robot noventa grados a mano. Si sale negativo, dejenlo negativo.

La magnitud ya esta resuelta sin mover nada: el driver reporta
`units = d/s` y `decimals = 1`, o sea que el entero crudo viene
multiplicado por diez, y por eso `IMU_ESCALA = 0.1`. No es el 0.001 de
EV3-G, donde el bloque oficial si entrega mili-grados/s. Lo que falta
confirmar con este comando es **el signo**.

```bash
python3 check_hw.py motores
```

Mueve 15 grados un motor a la vez, con aviso antes de cada uno, para
confirmar cual es la traccion y cual el volante. Levanten el robot o
ponganlo sobre un soporte.

```bash
python3 check_hw.py volante
```

Manda el volante a los dos topes logicos, para fijar `VOLANTE_SIGNO`.

## Correr

```bash
python3 open_ard.py
```

```bash
python3 obs_ard.py
```

Los dos: centran el volante, calibran el giroscopio con el robot inmovil,
esperan el boton central, corren las tres vueltas y frenan. El boton de
retroceso detiene todo en cualquier momento.

## Equivalencias con los programas de Arath

| Arduino / Mind+ | ev3dev |
|---|---|
| `mpu.prepararFacil` + `iniciar` + `calibrar(600)` | `Giroscopio.calibrar()` |
| `actualizar` + `zonaMuerta(0.3)` | `Giroscopio.actualizar()` |
| `angulo(Z)` / `reiniciarAngulos()` | `Giroscopio.grados` / `.reiniciar()` |
| cinco `readUltrasound` | `hub.actualizar()` |
| `map(((90i+25i)-(25d+90d))*-1, ...)` | `error_crudo()` por `VOLANTE_KP` |
| `Volante(error * 0.9)` | `Robot.girar_por_error()` |
| `Motor(velocidad)` | `Robot.avanzar()` |
| `millis()` | `time.time()` |
| `3 vueltas %n` | conteo de esquinas dentro del lazo de `obs_ard.py` |
| `actualizar Huskylens` | `HuskyLens.actualizar()` |
| `ERROR CAM = constrain(map(X+-100, ...))` | `HuskyLens.angulo_esquive()` |
| `huskylens.writeOSD` | telemetria por consola, `OBS_TELEMETRIA` |
| tira WS2812 segun esquinas | LEDs del ladrillo, `indicar_vuelta()` |

El esquive con camara se verifico numericamente: para todo X de 0 a 320 y
los dos IDs, `angulo_esquive()` da exactamente el mismo angulo que la
formula de Mind+, una vez trasladado el centro de 90 a 0.

## Diferencias deliberadas

**El factor 0.9.** En el original el error ya sale mapeado a 70..110 y
despues se multiplica por 0.9, lo que deja el rango en 63..99 y el centro
en 81, no en 90. Si el robot de Arath va recto con eso, ese 0.9 compensa
un desalineado mecanico del servo. Por eso se separo en `VOLANTE_KP`
(ganancia) y `VOLANTE_TRIM` (centro), que empieza en 0. Notese que el
camino de la camara **no** lleva ese 0.9, lo cual refuerza que era trim.

**Que bloque mira la camara.** Arath pide los dos primeros recuadros de
la HuskyLens y se queda con el mas ancho, y usa el indice del recuadro
como si fuera el color. El adaptador OFDL devuelve **un solo** recuadro
por lectura, pero devuelve su **ID aprendido de verdad**, que es mas
confiable que el indice. Lo que se pierde es el criterio de "el mas
ancho" cuando hay dos bloques a la vista a la vez. Hay que ver en pista
si el recuadro que entrega el adaptador es el mas grande o simplemente el
primero; `check_hw.py husky` con dos bloques delante lo resuelve en un
minuto.

**Llamadas repetidas.** El original llama a `actualizar Huskylens` tres
veces por vuelta de lazo y a `Actualizar Distancia` dos. Es ruido de
programacion por bloques; aqui se lee cada sensor una sola vez por vuelta.

**El sensor frontal.** Arath lo lee y no lo usa en ninguna decision. Aqui
se lee igual porque viene gratis en la misma trama, y queda en
`hub.frontal` para cuando haga falta.

## Lo que falta probar en pista

- Confirmar `IMU_ESCALA` y su signo.
- Confirmar los indices de los cinco ultrasonicos.
- Confirmar el ID de cada color en la HuskyLens.
- Medir cuantas vueltas de lazo por segundo salen de verdad. Los dos
  programas reportan al final cuantas tramas leyeron y cuantas salieron
  mal.
- Ajustar `VOLANTE_KP` y `HUSKY_DESPLAZAMIENTO_PX`: ese ultimo es cuanto
  se abre el rodeo alrededor del bloque.

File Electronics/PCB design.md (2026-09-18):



# PCB Design

This directory contains the hardware design files for the custom PCB used in the project.

The board is designed around an Arduino Nano and provides:
- Power input through a screw terminal.
- Regulated power distribution to multiple JST connectors.
- Dedicated input and output connectors for external peripherals.
- Optional I2C expansion header (EV3 compatible footprint).
- Enable (EN) control pads.
- Mounting holes for secure installation.
- Clearly labeled silkscreen for simplified assembly and debugging.

This PCB serves as the main interface board, simplifying wiring and providing a compact, reliable platform for connecting sensors, actuators, and expansion modules.

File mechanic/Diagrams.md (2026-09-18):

- FINAL PLATFORM diagram

| System | Implementation |
|:---|:---|
| Steering | Ackermann steering geometry |
| Drive System | Rear-wheel drive |
| Main Controller | LEGO Mindstorms EV3 Brick |
| Coprocessors | 2 Arduino Nano, 1 for the camera and one for the PCB |
| Vision System | HuskyLens AI Camera |
| Distance Measurement | Five ultrasonic sensors |
| Communication | I²C protocol and UART protocol |
| Electronics | Custom-designed PCB |
| Control Algorithm | Adaptive Dual PD Controller |
| Decision System | Finite State Machine |

---

- QUICK SYSTEM OVERVIEW diagram

                 ┌──────────────────┐               ┌────────────────┐
                 │ HuskyLens Camera │               │   Ultrasonic   │
                 └────────┬─────────┘               │  Sensors (x5)  │
                          │                         └───────┬────────┘
                          │ UART                            │
                          ▼                                 ▼
                 ┌──────────────────┐               ┌────────────────┐
                 │   Arduino Nano   │               │   Custom PCB   │
                 │      (UART)      │               └───────┬────────┘
                 └────────┬─────────┘                       │
                          │                                 ▼
                          │                         ┌────────────────┐
                          │                         │  Arduino Nano  │
                          │                         │     (I²C)      │
                          │                         └───────┬────────┘
                          │                                 │
                          └────────────────┬────────────────┘
                                           │
                                           ▼
                                   ┌────────────────┐
                                   │    LEGO EV3    │
                                   │   Controller   │
                                   └────────┬───────┘
                                            │
                            ┌───────────────┴───────────────┐
                            ▼                               ▼
                    ┌──────────────┐                ┌──────────────┐
                    │Steering Motor│                │  Drive Motor │
                    └──────────────┘                └──────────────┘

---

- TEAM RESPONSABILITIES diagram

| Area | Renato | Paulina |
|:---|:---:|:---:|
| Mechanical Design | ✅ | ✅ |
| Robot Assembly | ✅ | ✅ |
| Electronics Integration | | ✅ |
| PCB Installation | ✅ | ✅ |
| Software Development | ✅ | |
| EV3 Programming | ✅ | |
| Arduino Programming | ✅ | |
| Documentation | ✅ | ✅ |
| Testing & Validation | ✅ | ✅ |

---

- ENGINEERING HIGHLIGHTS diagram

| Feature | Implementation |
|:---|:---|
| Steering System | Ackermann steering geometry |
| Drive System | Rear-wheel drive |
| Sensors | Five ultrasonic sensors |
| Vision | HuskyLens AI camera |
| Coprocessors | 2 Arduino Nano, 1 for camera and 1 for pcb |
| Electronics | Custom PCB |
| Communication | I²C architecture |
| Steering Calibration | Automatic encoder-based calibration |
| Control | Adaptive Dual PD controller |
| Navigation | Finite State Machine |
| Software | Modular architecture |
| Sensor Mounting | Custom 3D printed supports |
| Mechanical Design | Optimized weight distribution |

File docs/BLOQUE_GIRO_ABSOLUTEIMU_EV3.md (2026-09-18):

# Bloque de giro para mindsensors AbsoluteIMU-ACG y EV3

El proyecto `ev3/WRO 26 I2C MULTI IMU.ev3` contiene el bloque personalizado **IMU_ANGULO**. Este bloque convierte la velocidad angular del eje Z en:

- **Z corregida:** velocidad de giro en grados por segundo.
- **GRADOS:** giro acumulado con signo; no se limita a 0–360.
- **VUELTAS:** giro acumulado dividido entre 360.

## Conexión recomendada

Monte el AbsoluteIMU plano y firme, con el eje Z perpendicular al piso. Conecte el sensor directamente a un puerto de sensores EV3 (1–4); no lo conecte al multiplexor de ultrasonidos.

En EV3-G, use el bloque oficial **Mindsensors-ABSIMU**, modo **Read Gyro**, y conecte su salida **Z Gyro** a la entrada **Z del sensor** de `IMU_ANGULO`.

Los datos del bloque oficial están en mili-grados por segundo. Por ello:

- **ESCALA = 0.001** con el bloque oficial Mindsensors-ABSIMU.
- **ESCALA = 1** si la lectura que entra ya está en grados por segundo, por ejemplo con el bloque Dexter corregido incluido en esta carpeta.
- **TIMER = 8** de forma predeterminada. No use el temporizador 8 en otra parte del programa mientras esté contando el giro.

## Uso

1. Deje inmóvil el robot al iniciar.
2. Lea varias veces `Z Gyro` durante uno o dos segundos y calcule el promedio. Escriba ese promedio en **OFFSET**. Si en reposo entrega aproximadamente cero, empiece con `OFFSET = 0`.
3. Antes de empezar el recorrido, llame una vez a `IMU_ANGULO` con **REINICIAR = verdadero**. Esta llamada pone GRADOS y VUELTAS en cero y prepara el temporizador.
4. Dentro del bucle principal, lea primero **Z Gyro** y después llame a `IMU_ANGULO` con **REINICIAR = falso**.
5. Use **GRADOS** para giros como 90°, 180° o 720°. Use **VUELTAS** si resulta más cómodo: 1 vuelta = 360°, 2.5 vueltas = 900°.

No agregue un bloque de espera largo dentro de este lazo. El bloque mide el tiempo real transcurrido con el temporizador EV3, de modo que sigue contando aunque el periodo del lazo varíe.

## Sentido del giro

El signo depende de la orientación física del sensor. Si al girar a la derecha los grados disminuyen y desea que aumenten, cambie **ESCALA** a `-0.001` (bloque oficial) o `-1` (lectura ya expresada en grados/s).

## Precisión para WRO

El giroscopio acumula cualquier pequeño error de offset. Calibre con el robot totalmente quieto, evite vibraciones y reinicie el contador justo antes de cada maniobra o tramo. Para giros cortos y repetibles conviene frenar unos grados antes del objetivo y terminar a menor velocidad.

La brújula del AbsoluteIMU puede ayudar a corregir deriva a largo plazo, pero cerca de motores, cables de potencia y estructuras metálicas suele sufrir interferencias; para contar vueltas completas el acumulador del giroscopio es la opción principal.

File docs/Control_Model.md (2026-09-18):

# 🧮 Mathematical Control Model

<div align="center">

**Los Grises Jr — WRO 2026 Future Engineers**

*Sensor fusion · Error · Control law · Kinematics · Torque · Steering geometry*

Every constant here is traceable either to a measurement on the robot or
to a line in [`Src/ev3dev/wro/config.py`](../Src/ev3dev/wro/config.py).
Where a value is an estimate rather than a measurement, it says so.

</div>

---

## 🚗 1. Vehicle Parameters

| Parameter | Symbol | Value |
|:---|:---:|---:|
| Mass | $m$ | **861 g** = 0.861 kg |
| Overall dimensions | — | 24 × 23 × 18 cm |
| Wheel diameter | $D$ | 56.0 mm |
| Wheel radius | $r$ | 28.0 mm = 0.028 m |
| Wheel circumference | $C$ | 175.93 mm |
| Wheelbase | $L_b$ | 24.0 cm |
| Track width | $W_t$ | 18.0 cm |
| Motor encoder resolution | — | 1° |
| Drive motor | — | EV3 Medium, port B |
| Steering motor | — | EV3 Medium, port A |

$$C = \pi D = \pi \times 56.0 = 175.93\ \text{mm}$$

---

## 📐 2. Wall-Centring Geometry

### 2.1 Sensor layout

Four lateral ultrasonic sensors, two per side: one perpendicular to the
chassis (90°) and one angled. A fifth sensor faces forward and is read
but not used in any control decision.

Let the corridor width be $W = 100\ \text{cm}$ and let $d$ be the lateral
displacement from the centre line, positive towards the left wall.

The perpendicular sensors measure:

$$r_{90}^{L} = \frac{W}{2} - d \qquad r_{90}^{R} = \frac{W}{2} + d$$

The angled sensors are mounted at **25° from perpendicular**. Their range
is therefore the perpendicular distance divided by $\cos 25°$:

$$r_{25} = \frac{1}{\cos 25°}\cdot r_{90} = 1.103\,r_{90}$$

### 2.2 The error signal

Each side is summed, and the error is the negated difference between
sides:

$$e = -\Big[(r_{90}^{L} + r_{25}^{L}) - (r_{25}^{R} + r_{90}^{R})\Big]$$

$$e = -\Big[(1 + 1.103)\left(\tfrac{W}{2} - d\right) - (1 + 1.103)\left(\tfrac{W}{2} + d\right)\Big]$$

$$\boxed{\;e = 2\,(1 + 1.103)\,d = 4.21\,d\;}$$

**The error is 4.21 times the physical displacement.** All four sensors
move at once — two approach the wall while two recede — so their
contributions add rather than cancel. This is why the error grows several
times faster than the displacement, and why the proportional gain looks
small next to the numbers involved.

> [!IMPORTANT]
> **Verification.** The model predicts $e = 42$ for a 10 cm displacement.
> Measured on track, a 10 cm displacement produces an error of
> approximately 40 — within 5 %, consistent with sensor tolerance.

### 2.3 Why the negation matters

If the robot drifts towards the **left** wall, $d > 0$, the left readings
fall, and $e$ comes out **positive**. A positive steering command turns
**right**, away from the wall.

The sign is what closes the loop. Without the negation the robot would
steer into the wall it is already approaching.

### 2.4 Decomposing a diagonal reading

A diagonal sensor's range splits into lateral and forward components:

$$Y_{\text{wall}} = D_{\text{diag}}\cos 25° = 0.906\,D_{\text{diag}}
\qquad
X_{\text{forward}} = D_{\text{diag}}\sin 25° = 0.423\,D_{\text{diag}}$$

This is what makes the angled sensors useful: the forward component means
they see a corner slightly before the perpendicular pair does.

---

## 🎮 3. The Wall-Centring Controller

### 3.1 Control law

$$\delta = \mathrm{clamp}\big(K_p \cdot e,\; -L_{\text{izq}},\; +L_{\text{der}}\big)$$

where $\delta$ is the steering angle in motor degrees relative to centre.

**There is no derivative or integral term.** That is a measured decision,
not an omission. The tuning log in [`Logs_Tuning.md`](Logs_Tuning.md)
records the integral term saturating the steering actuator on track
imperfections — corners generate a sustained error for a short period,
the integral accumulates it, and the steering deviates from its
geometric response.

### 3.2 Saturation: what the gain actually means

A proportional controller is only meaningful up to the point where it
saturates:

$$e_{\text{sat}} = \frac{L}{K_p}
\qquad\qquad
d_{\text{sat}} = \frac{e_{\text{sat}}}{4.21} = \frac{L}{4.21\,K_p}$$

With the measured limit $L = 50.6°$:

| $K_p$ | $e_{\text{sat}}$ | $d_{\text{sat}}$ | Character |
|:---:|:---:|:---:|:---|
| 10 | 5.1 | **1.2 cm** | Effectively bang-bang |
| 3 | 16.9 | **4.0 cm** | Narrow proportional band |
| 1.5 | 33.7 | **8.0 cm** | Wide proportional band |
| 0.47 | 107 | — | Never saturates in a 1 m corridor |

`config.py` computes $e_{\text{sat}}$ automatically as
`VOLANTE_ERROR_TOPE`, so the meaning of a gain sits next to the gain.

> [!CAUTION]
> **A gain can silently compensate for broken hardware.** We ran
> $K_p = 10$ while one ultrasonic sensor was dead. With its readings
> substituted by the filter, the error sat at a constant $+62$ — nearly
> four times the saturation point — and the steering was pinned at full
> lock regardless of the walls. After repair the true operating error was
> 5 to 9, and $K_p = 10$ saturated permanently. **The gain had been
> masking the fault.**

### 3.3 Speed and correction distance

At loop rate $f$ and forward speed $v$, the robot travels

$$\Delta s = \frac{v}{f}$$

between consecutive steering updates. At the measured
$f \approx 30\ \text{Hz}$, each correction covers 33 ms of travel.
Raising $v$ without raising $f$ increases $\Delta s$, which is why a
faster robot needs more gain for the same correction to arrive in time —
and why, past a point, weaving is a symptom of the loop rate rather than
of the gain.

---

## ⚙️ 4. Motor Kinematics and Linear Displacement

### 4.1 Distance from motor angle

$$d = \frac{\theta}{360°}\cdot C$$

$$\frac{C}{360} = \frac{175.93}{360} = 0.4887\ \text{mm/degree}$$

$$\theta = \frac{d}{0.4887}$$

The encoder resolves 1°, so the theoretical position quantum is
**0.49 mm** of wheel travel. That is the floor on odometric precision
before slip is considered.

### 4.2 Speed command to linear velocity

Speed is commanded as a percentage of the motor maximum:

$$\omega_{\text{cmd}} = \frac{v_{\%}}{100}\,\omega_{\max},
\qquad \omega_{\max} = 1560\ °/\text{s}$$

Converting to linear wheel speed:

$$v = \frac{\omega_{\text{cmd}}}{360}\cdot C$$

| $v_\%$ | $\omega_{\text{cmd}}$ | $v$ at the wheel |
|---:|---:|---:|
| 40 | 624 °/s | 0.305 m/s |
| 50 | 780 °/s | 0.381 m/s |
| 70 | 1092 °/s | 0.534 m/s |
| 100 | 1560 °/s | 0.763 m/s |

> [!NOTE]
> These assume direct drive from motor to wheel. Any gear reduction
> scales them down proportionally, and should be measured rather than
> assumed.

---

## 🔩 5. Torque, Traction and Acceleration

### 5.1 Available force

The EV3 Medium Motor has a reference running torque of
$\tau = 8\ \text{N·cm} = 0.08\ \text{N·m}$ and a stall torque of
$0.12\ \text{N·m}$. Stall torque is a blocked-rotor figure, not a driving
condition.

$$F = \frac{\tau}{r} = \frac{0.08}{0.028} \approx 2.86\ \text{N}$$

### 5.2 What the mass makes of it

With $m = 0.861\ \text{kg}$:

$$a_{\max} = \frac{F}{m} = \frac{2.86}{0.861} \approx 3.32\ \text{m/s}^2$$

$$W = mg = 0.861 \times 9.81 \approx 8.45\ \text{N}$$

### 5.3 The slip condition

Tractive force cannot exceed what friction can transmit:

$$F \le \mu\,N$$

Taking the full weight on the driven axle as an upper bound:

$$\mu_{\text{required}} \ge \frac{F}{W} = \frac{2.86}{8.45} \approx 0.34$$

Rubber on a smooth competition surface typically gives $\mu$ well above
0.34, so the robot should be **torque-limited rather than
traction-limited** under normal acceleration.

> [!IMPORTANT]
> The rear-wheel-drive layout puts only part of the mass on the driven
> axle, which raises the effective $\mu$ required. This was observed at
> the highest speeds tested, where the chassis began to drift on rear-tyre
> slip — the ideal kinematic model stops being accurate there.

### 5.4 Time to reach speed

$$t = \frac{v}{a_{\max}}$$

| Target | $v$ | $t$ (ideal) |
|---:|---:|---:|
| $v_\% = 40$ | 0.305 m/s | 0.09 s |
| $v_\% = 70$ | 0.534 m/s | 0.16 s |

These are upper-bound figures: they ignore drivetrain losses, rolling
resistance and the motor's own speed-torque curve, all of which reduce
available torque as speed rises.

---

## 🔄 6. Steering Geometry

### 6.1 Ackermann condition

With wheelbase $L_b$ and track width $W_t$, for a commanded steering
angle $\alpha$ the inner and outer wheels must take different angles to
share a turning centre:

$$\delta_{\text{inner}} = \arctan\!\left(\frac{L_b}{\dfrac{L_b}{\tan\alpha} - \dfrac{W_t}{2}}\right)
\qquad
\delta_{\text{outer}} = \arctan\!\left(\frac{L_b}{\dfrac{L_b}{\tan\alpha} + \dfrac{W_t}{2}}\right)$$

The turning radius measured to the centre of the rear axle is

$$R = \frac{L_b}{\tan\alpha}$$

With $L_b = 24.0\ \text{cm}$ and $W_t = 18.0\ \text{cm}$:

| $\alpha$ | $R$ | $\delta_{\text{inner}}$ | $\delta_{\text{outer}}$ |
|---:|---:|---:|---:|
| 10° | 136 cm | 10.7° | 9.4° |
| 20° | 66 cm | 22.0° | 18.4° |
| 30° | 42 cm | 34.0° | 26.9° |

Satisfying this geometry is what stops the inner wheel from scrubbing
through a turn.

> [!WARNING]
> **Open item: $L_b$ and $W_t$ need re-measuring.** The values above,
> 24.0 cm and 18.0 cm, are identical to the robot's overall **length** and
> **height** from the specification table (24 × 23 × 18 cm). Wheelbase is
> measured axle to axle and is necessarily shorter than the vehicle;
> track width is measured between wheel centres. These figures appear to
> have been taken from the bounding box rather than from the chassis.

### 6.2 Steering travel measurement

The steering is driven against both mechanical stops. Two distinct
quantities result:

| Quantity | Measured | Meaning |
|:---|---:|:---|
| $T_{\text{forced}}$ | $153°$ | Stop to stop at 100 % duty |
| $T_{\text{free}}$ | $119°$ | Reached at minimum duty |

The difference of $34°$ is **not steering**. It is the mechanism flexing
against the stops under load; it does not become wheel angle.

### 6.3 Deriving the limit

$$L = \frac{T_{\text{free}}}{2}\times 0.85 = \frac{119}{2}\times 0.85 = 50.6°$$

The factor 0.85 leaves a 15 % margin so the steering does not strike its
stops on every correction. Taking the limit from $T_{\text{forced}}$
would give $65°$, and the steering would spend the race fighting its own
end stops.

### 6.4 Centre and per-side limits

$$c = \frac{p_{+} + p_{-}}{2}$$

the midpoint of the two forced extremes. The forced travel is used
because both ends are reached the same way; the free ends are reached one
from centre and one from a stop, and are therefore not symmetric.

$$L_{\text{der}} = L\,f_{\text{der}} \qquad L_{\text{izq}} = L\,f_{\text{izq}}
\qquad f \in [0,1]$$

Expressing the clamp as a fraction keeps $L$ as the mechanical ceiling and
the fractions as the tuning knob, so re-measuring the mechanism rescales
both sides automatically.

---

## 👁 7. Camera Avoidance

### 7.1 Image coordinates

The HuskyLens reports a bounding box in a $320\times 240$ image. The
horizontal coordinate is re-centred:

$$X = X_{\text{raw}} - 160 \qquad X \in [-160,\,+160]$$

### 7.2 Control law

$$\delta_{\text{cam}} = \mathrm{clamp}\!\left(\frac{L}{160}\,(X - X_{\text{target}}),\;\text{lo},\;\text{hi}\right)$$

The gain is fixed by geometry, not tuned:

$$\frac{L}{160} = \frac{50.6}{160} = 0.316\ \text{degrees per pixel}$$

| Colour | ID | $X_{\text{target}}$ | Block ends up | Robot passes |
|:---|:---:|:---:|:---|:---|
| Red | 1 | $-150$ | Left of frame | **Right** of the pillar |
| Green | 2 | $+150$ | Right of frame | **Left** of the pillar |

The inversion is not a sign error. The camera looks where the robot is
**going**: to leave a pillar on your left, you must point to the right of
it.

### 7.3 Why the target must lie inside ±160

For the controller to converge there must exist a reachable $X$ with
$\delta_{\text{cam}} = 0$, which requires

$$\boxed{\;|X_{\text{target}}| \le 160\;}$$

If $X_{\text{target}} = 180$, then even at the extreme $X = 160$:

$$\delta_{\text{cam}} = 0.316\,(160-180) = -6.3°$$

The steering never straightens while the block is in view. At
$X_{\text{target}} = 150$ the proportional band covers
$X \in [-10,\,150]$ and the loop closes at $X = 150$.

### 7.4 Measured convergence

| $X$ | $\delta_{\text{cam}}$ |
|---:|---:|
| $+116$ | $-7.6$ |
| $+127$ | $-4.1$ |
| $+133$ | $-2.2$ |
| $+139$ | $-0.3$ |
| $+143$ | $+0.9$ |

$X$ climbs monotonically to the target, $\delta$ shrinks to zero and
crosses sign. The loop closes as predicted.

---

## 📡 8. Sensor Dropout Filtering

### 8.1 The sentinel problem

With no echo, the firmware reports $125$ and clears the sensor's validity
bit. **125 is a sentinel, not a distance.** Treated as one, a dropout
changes that side's sum by

$$\Delta = 125 - r_{\text{actual}}$$

With a typical $r_{\text{actual}} \approx 20\ \text{cm}$ that is
$\Delta \approx 105$, over six times $e_{\text{sat}}$ at $K_p = 3$.

**Measured with the robot standing still:** the error swung from $+5$ to
$-82$ and back to $+31$ in under one second.

### 8.2 The three-state filter

$$
r_{\text{used}} =
\begin{cases}
r & \text{valid, and } r < 125 \\[4pt]
r_{\text{last good}} & t - t_g \le T_{\text{hold}} \\[4pt]
r_{\max} & t - t_g > T_{\text{hold}}
\end{cases}
$$

with $T_{\text{hold}} = 0.5\ \text{s}$ and $r_{\max} = 100\ \text{cm}$,
followed by a rolling median of three.

### 8.3 Substitution rate as a health metric

$$\rho_i = \frac{n_{\text{sub},i}}{n_{\text{frames}}}$$

Measured: $\rho \approx 0$ for healthy sensors, $\rho = 0.25$ to $0.34$
for a faulty one. **A sensor above a few percent is a hardware fault**,
and no gain compensates for a quarter of its readings being fabricated.

---

## 🧭 9. Heading and Corner Counting

### 9.1 Integration

$$\theta_k = \theta_{k-1} + \omega_k\,\Delta t_k,
\qquad \omega_k = (\text{raw}_k - \bar b)\,s$$

$\Delta t_k$ is the **measured** elapsed time, not the nominal loop
period, so a varying loop rate introduces no bias.

### 9.2 The scale factor

$$s = 0.1$$

Exact by construction: the `ms-absolute-imu` driver in GYRO mode reports
`units = d/s` with `decimals = 1`, so the raw integer is ten times the
value in degrees per second.

**Independent check.** Integrating one full manual rotation gave
$s = 0.09795$, within 2 %. The exact value is kept; the measurement
confirmed the axis and the sign.

### 9.3 Bias calibration

$$\bar b = \frac{1}{N}\sum_{k=1}^{N}\text{raw}_k, \qquad N = 600$$

Averaging reduces the bias uncertainty by $\sqrt N = 24.5$. This matters
because bias error **integrates**: a residual $\varepsilon$ produces
drift $\varepsilon t$, growing without bound over a three-lap run.

### 9.4 Dead band

$$\omega_{\text{used}} =
\begin{cases} 0 & |\omega| < 0.3\ °/\text{s}\\ \omega & \text{otherwise}\end{cases}$$

Any residual bias below $0.3\ °/\text{s}$ contributes exactly zero while
driving straight, **bounding** drift rather than merely reducing it.

### 9.5 Corner detection

$$|\theta| \ge 87° \quad\text{and}\quad t - t_{\text{last}} \ge 1.5\ \text{s}$$

**87° rather than 90°** absorbs the small undershoot from the dead band
and from discrete integration.

**The 1.5 s interval** exists because the gyroscope cannot distinguish a
track corner from an avoidance manoeuvre: when the camera sends the
steering to full lock, the robot genuinely rotates and genuinely
accumulates 87°.

> [!CAUTION]
> **Measured failure.** During an obstacle run, two corners were counted
> **1.1 s apart**, where real corners were arriving every **6 s**. Each
> false corner brings the target of twelve closer; the robot would brake
> mid-track believing it had finished.

A rejected turn still resets $\theta$, because that rotation physically
happened and carrying it forward would trigger the following corner
early.

---

## 🔋 10. Supply Voltage as a Hidden Parameter

The EV3 motor output scales with battery voltage.

**Measured at $v_\% = 80$**, two identical tests minutes apart:

| Battery | Commanded | Achieved | Ratio |
|---:|---:|---:|---:|
| ~7.4 V | 1248 °/s | 1219 °/s | **98 %** |
| ~7.2 V | 1248 °/s | 1093 °/s | **88 %** |

The drive motor is commanded in **velocity** mode, so the EV3 regulates
on the encoder and compensates for load. It cannot compensate for a
supply that can no longer deliver the power.

> [!IMPORTANT]
> Gains tuned on a half-charged battery do not reproduce on a full one.
> Battery voltage is recorded before each tuning session.

---

## 📊 11. Reference Values

### Physical

| Parameter | Value | Meaning |
|:---|---:|:---|
| Mass | **861 g** | Complete vehicle, as raced |
| Weight | 8.45 N | $mg$ |
| Overall dimensions | 24 × 23 × 18 cm | Within the 30 × 30 × 30 limit |
| Wheel diameter $D$ | 56.0 mm | Drive wheel |
| Wheel circumference $C$ | 175.93 mm | $\pi D$ |
| Linear distance per degree | 0.4887 mm/° | $C/360$ |
| Wheelbase $L_b$ | 24.0 cm | ⚠️ re-measure, see §6.1 |
| Track width $W_t$ | 18.0 cm | ⚠️ re-measure, see §6.1 |
| Motor resolution | 1° | EV3 encoder |
| Running torque | 0.08 N·m | Reference operating torque |
| Stall torque | 0.12 N·m | Blocked rotor, not a driving figure |
| Tractive force | ≈ 2.86 N | $\tau / r$, ideal |
| Max acceleration | ≈ 3.32 m/s² | $F/m$, ideal |
| Required friction | $\mu \ge 0.34$ | Not to slip at full torque |
| Motor max speed | 1560 °/s | EV3 Medium |

### Control

| Symbol | Constant | Value | Origin |
|:---|:---|---:|:---|
| $L$ | `VOLANTE_LIMITE` | 50.6° | Derived, §6.3 |
| $K_p$ | `VOLANTE_KP` | 3 | Tuned on track |
| $K_{p,\text{obs}}$ | `VOLANTE_KP_OBSTACULOS` | 1.5 | Tuned on track |
| $e_{\text{sat}}$ | `VOLANTE_ERROR_TOPE` | 16.9 | Derived, §3.2 |
| — | `VOLANTE_VELOCIDAD` | 600 °/s | Steering slew rate |
| $s$ | `IMU_ESCALA` | 0.1 | Exact, §9.2 |
| $N$ | `IMU_MUESTRAS_CALIBRACION` | 600 | §9.3 |
| $\omega_{\min}$ | `IMU_ZONA_MUERTA` | 0.3 °/s | §9.4 |
| — | `ANGULO_ESQUINA` | 87° | §9.5 |
| — | `ESQUINA_INTERVALO_MINIMO` | 1.5 s | Measured, §9.5 |
| $T_{\text{hold}}$ | `ARD_RETENCION` | 0.5 s | §8.2 |
| $r_{\max}$ | `ARD_DISTANCIA_MAXIMA` | 100 cm | Corridor width |
| — | `HUSKY_TARGET_ROJO` | −150 px | §7.2 |
| — | `HUSKY_TARGET_VERDE` | +150 px | §7.2 |
| — | `HUSKY_RETENCION` | 0.15 s | Measured |
| — | `HUSKY_MARGEN_ANCHO` | 1.2 | Hysteresis |
| $v_\%$ | `VELOCIDAD` | 70 | Open challenge |
| $v_\%$ | `VELOCIDAD_OBSTACULOS` | 40 | Obstacle challenge |
| $f$ | — | ≈ 30 Hz | Measured loop rate |

---

## 🔬 12. Open Items

Values that need a measurement rather than a decision:

| Item | Why it matters | Section |
|:---|:---|:---:|
| Wheelbase and track width | Current figures match the bounding box, not the chassis | §6.1 |
| Gear ratio, motor to wheel | Every linear speed in §4.2 assumes direct drive | §4.2 |
| Mass on the driven axle | Sets the real slip threshold, not the total weight | §5.3 |

---

<div align="center">

**Los Grises Jr** · World Robot Olympiad 2026 · Future Engineers

</div>

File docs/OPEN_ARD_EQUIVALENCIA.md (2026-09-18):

# OPEN_ARD: replica en EV3 del programa Arduino de la prueba abierta

Archivo nuevo: `ev3/WRO 26 OPEN ARD.ev3`, programa `OPEN_ARD`.

Es una copia completa del proyecto `ev3/WRO 26.ev3` mas un programa adicional.
El proyecto original no se modifico. Los unicos cambios respecto de el son:

- se agrego el archivo `OPEN_ARD.ev3p`;
- en `Project.lvprojx` se registro ese archivo y se declaro la variable global `ESQUINAS`.

Todos los demas programas y bloques (`OPEN`, `OBSTACULOS`, `ESTACIONAMIENTO`,
`PID_R_20`, `ARD`, `ERROR`, `INICIO`, los bloques IMU, etc.) siguen exactamente
igual.

## Origen

Se replico la pagina activa de `WRO Arath Nacional/mind+/WRO OPEN ARD-UNO.mp`
(Arduino UNO). Ese programa es:

```
Inicio:
  limites = 20
  esquinas = 0
  MPU6050 en 0x68: preparar, iniciar, calibrar con 600 muestras

Bucle:
  actualizar IMU
  zona muerta 0.3
  Distancia()
  Motor(velocidad)
  Volante(error * 0.9)
  si anguloZ >= 87 o anguloZ <= -87:
      reiniciar angulos
      esquinas = esquinas + 1
  si esquinas >= 12:
      tiempo = millis() + 200
      repetir hasta millis() >= tiempo: Distancia(); Motor(velocidad); Volante(error*0.9)
      velocidad = 0
  si no:
      velocidad = 60
  LEDs WS2812 segun esquinas == 4 / 8 / 12

Distancia():
  25izq   = ultrasonico(trig 4,  echo 5)
  frontal = ultrasonico(trig 4,  echo 6)      <- se lee pero no se usa
  25der   = ultrasonico(trig 4,  echo 7)
  90izq   = ultrasonico(trig 13, echo 2)
  90der   = ultrasonico(trig 13, echo 3)
  error   = map( ((90izq + 25izq) - (25der + 90der)) * -1, -100, 100, 70, 110 )

Motor(v):    pin9 LOW, pin10 HIGH, PWM pin11 = map(v, 0,100, 0,255)
Volante(a):  servo pin 8 = a
```

## Equivalencias

| Arduino | EV3 |
|---|---|
| `Inicio` (limites, serial, reset) | bloque `INICIO` (reinicia volante, encoders B y C, `SUMA`, `LINEAS`, pantalla, LED) |
| `esquinas = 0` | `ESQUINAS = 0` (variable global nueva) |
| `velocidad = 60` | `VEL = 60` antes del bucle |
| `mpu.calibrar(600)` | `IMU_Calibrar_WRO` puerto 1.2, direccion 34, temporizador 8 |
| `Distancia()` + calculo de `error` | bloque `ERROR`, que lee `ARD` indices 1, 2, 4, 5 y hace `(izq1+izq2) - (der1+der2)` |
| `Volante(error * 0.9)` | `PID_R_20` con `Entrada Numero = ERROR`, KP 0.3, KI 0, KD 0, POTENCIAMAX 30, LIM 20 |
| `Motor(velocidad)` | `MotorUnlimited` puerto 1.D con potencia leida de `VEL` |
| `actualizar` + `angulo(Z)` | `IMU_Giro_WRO` puerto 1.2, direccion 34, temporizador 8, Reiniciar = falso, salida **Grados** |
| `anguloZ >= 87 o <= -87` | `valor absoluto(Grados) >= 87` |
| `reiniciarAngulos()` | `IMU_Giro_WRO` con **Reiniciar = verdadero** dentro del caso verdadero |
| `esquinas = esquinas + 1` | leer `ESQUINAS`, sumar 1, escribir `ESQUINAS` |
| `esquinas >= 12` -> salir | comparacion `ESQUINAS >= 12` conectada a **Detener si verdadero** del bucle |
| avanzar 200 ms mas y `velocidad = 0` | esperar 0.2 s, luego `MotorStop` 1.D, `MediumMotorStop` 1.B, `VEL = 0`, `reinicio_volante` |

## Diferencias deliberadas

**Servo contra PID.** En Arduino el volante es un servo: `error` ya sale mapeado
a 70..110 grados y luego se multiplica por 0.9. El EV3 mueve el volante con el
motor mediano B a traves de `PID_R_20`, que recibe el error crudo. Por eso no se
copian ni el `map` ni el factor 0.9: se usan las ganancias que ya estaban
probadas en el programa `OPEN` existente (KP 0.3, KI 0, KD 0, POTENCIAMAX 30,
LIM 20). Es el punto a ajustar en pista.

Nota sobre el original: `error` mapeado a 70..110 y luego multiplicado por 0.9 da
63..99, es decir centro 81 y no 90. Si en el robot de Arduino el volante queda
recto, ese 0.9 esta actuando como compensacion mecanica, no como ganancia.

**Zona muerta.** `zonaMuerta(0.3)` es de la extension MPU6050 de Mind+. El bloque
`IMU_Giro_WRO` del AbsoluteIMU ya trae su propia correccion de cero por
calibracion, asi que no se replico.

**LEDs WS2812.** No hay tira de LEDs en el EV3, asi que el indicador de vuelta
(4, 8, 12 esquinas) no se replico. Si lo quieren, el equivalente natural es
mostrar `ESQUINAS` en la pantalla del ladrillo con un bloque de texto.

**Frontal.** El ultrasonico frontal se lee en Arduino pero no se usa en ninguna
decision, asi que en EV3 no se lee.

**MPU6050 contra AbsoluteIMU.** Arduino usa MPU6050 en 0x68 por I2C directo; el
EV3 usa el mindsensors AbsoluteIMU en el puerto 2, direccion 34 (0x22).

## Hardware que asume el programa

- Puerto de sensores **2**: mindsensors AbsoluteIMU (direccion I2C 34).
- Puerto de sensores **4**: Arduino Nano multiplexor de ultrasonicos (direccion I2C 8), leido por el bloque `ARD`.
- Puerto de motores **B**: motor mediano del volante (lo maneja `PID_R_20`).
- Puerto de motores **D**: motor de traccion.

## Para probar

1. Abrir `ev3/WRO 26 OPEN ARD.ev3` en LEGO MINDSTORMS Education EV3.
2. Abrir el programa `OPEN_ARD`.
3. Dejar el robot inmovil hasta que termine `IMU_Calibrar_WRO`; si se mueve, el
   cero del giroscopio queda mal y el conteo de esquinas falla.
4. Verificar el sentido de giro: si al girar a la derecha **Grados** baja en vez
   de subir, no importa para el conteo porque se compara el valor absoluto, pero
   si importa para el signo del error del PID.
5. Ajustar KP y POTENCIAMAX del bloque `PID_R_20` dentro del bucle.

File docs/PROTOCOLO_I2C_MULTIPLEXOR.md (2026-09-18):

# Protocolo I2C del multiplexor de cinco ultrasonicos

El Arduino Nano trabaja como esclavo I2C en la direccion `0x08`. En el bloque
Dexter esta direccion se introduce como `8`.

Cada lectura devuelve ocho bytes:

| Byte | Contenido |
|---:|---|
| 0 | Distancia del sensor 1 en cm |
| 1 | Distancia del sensor 2 en cm |
| 2 | Distancia del sensor 3 en cm |
| 3 | Distancia del sensor 4 en cm |
| 4 | Distancia del sensor 5 en cm |
| 5 | Mascara de validez; los bits 0 a 4 corresponden a los sensores 1 a 5 |
| 6 | Contador de trama, de 0 a 255 |
| 7 | Checksum XOR de los bytes 0 a 6 |

El valor `125` se usa como distancia de sustitucion cuando no hay eco o la
medicion queda fuera del rango configurado. Para distinguir un `125` real de un
fallo se debe consultar el bit correspondiente del byte de estado.

En EV3-G, el bloque `MUX_I2C_5` usa internamente `Read I2C 8 Bytes` de Dexter y
presenta los ocho campos como salidas numericas. Requiere tener importado el
paquete Dexter que contiene `readi2c_8b.vix`.

## Correccion de bytes negativos en Read I2C 1 Byte

Algunas versiones del bloque Dexter convierten directamente el byte recibido a
un numero con signo. Por eso un valor de `168` aparece en EV3-G como `-88`.
La conversion a byte sin signo es:

```text
si lectura < 0: lectura_corregida = lectura + 256
si lectura >= 0: lectura_corregida = lectura
```

El paquete `Dexter_I2C_Unsigned_Fix.ev3b` incorpora esta conversion dentro de
`Read I2C 1 Byte`. Tambien conserva el arreglo anterior de las entradas de
escritura para permitir valores de `0` a `255`.

Para validar una trama en EV3, calcule XOR sobre las primeras siete salidas y
compare el resultado con `CHECKSUM`. El contador `TRAMA` permite saber si el
Arduino termino un ciclo nuevo de cinco mediciones.

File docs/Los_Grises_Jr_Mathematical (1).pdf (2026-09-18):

Los Grises Jr • WRO 2026 | Page 1

# LOS GRISES JR

WRO 2026 • Software & Mathematical Control Documentation

MATHEMATICAL CONTROL MODEL Sensor fusion • Error • PID • VEL • Kinematics • Torque • Steering

## 1. Software Architecture

The control system is organized into sensor acquisition, sensor fusion, obstacle detection, PID motion control, speed control through VEL, motor control, and a safety override.
- Sensor acquisition: reads the four ultrasonic sensors.
- Sensor fusion: combines the 90° and 45° measurements into the control error.
- Obstacle detection: uses the front ultrasonic sensor for the safety condition.
- PID motion control: converts ERROR into a steering correction.
- VEL control: defines the numerical speed command used by the program.
- Motor control: applies the resulting command to the drive motors.
- Safety override: takes priority when the front obstacle threshold is reached.

## 2. Software Execution Flow

→ Initialize the drive system.
→ Read the front ultrasonic sensor.
→ Store the measurement as ARD.
→ If ARD < 25 cm, stop, wait a few milliseconds, and reverse 0.5 motor rotations. → Otherwise, read the four lateral ultrasonic sensors.
→ Calculate the sensor differences and then ERROR.
→ Set the programmed VEL numerical command.
→ Calculate/update the PID terms.
→ Apply the motor command.

## 3. Ultrasonic Sensor Configuration

The robot uses exactly four lateral ultrasonic sensors: two sensors at 90° and two sensors at 45°. The 90° pair provides direct lateral measurements, while the 45° pair provides diagonal measurements.

### S90,1, S90,2 → direct lateral distances S45,1, S45,2 → diagonal distances

## 4. Error Calculation

### 4.1 Sensor differences

E90 = S90,1 − S90,2

This difference represents the imbalance measured by the two 90° sensors. E45 = S45,1 − S45,2

This difference represents the imbalance measured by the two 45° sensors.

### 4.2 Final control error

### ERROR = (S90,1 − S90,2) − (S45,1 − S45,2) + 100

### ERROR = E90 − E45 + 100

The +100 is a calibration/control offset established for the sensor configuration. It shifts the numerical error to the reference value used by the robot's control system. It is a control-system offset, not a physical distance, force, or torque.

## 5. PID Motion Controller

### I(t) = I(t−1) + ERROR(t)

Integral: accumulates error over time, allowing correction of persistent deviation.

### D(t) = ERROR(t) − ERROR(t−1)

Derivative: measures how quickly the error changes.

### PID_Output = Kp

### ·ERROR + Ki

### ·I + Kd

·D

- P: responds to the current error.
- I: responds to accumulated error.
- D: responds to the change in error.
- The gains Kp, Ki and Kd are tuned through real-track testing.

## 6. Speed Control — VEL

VEL is treated as a numerical value in the control program. The programmed command uses the 40–50 numerical offset:

### VEL_command = VEL_base + 40

### VEL_command = VEL_base + 50

The selected programmed value is therefore VEL_base + 40 or VEL_base + 50, according to the corresponding robot condition/configuration.

## 7. Front Ultrasonic Safety System

### If ARD < 25 cm → STOP → WAIT → REVERSE 0.5 rotations

The front-obstacle condition has priority over the normal steering loop. The reverse command is fixed at 0.5 motor rotations.

## 8. Motor Kinematics & Linear Displacement

### 8.1 Wheel circumference

### C = πD

For D = 56.0 mm:

### C = π(56.0) ≈ 175.93 mm

### 8.2 Distance from motor angle

### d = (θ / 360°) · C

d

1° = 175.93 / 360 ≈ 0.4887 mm/° θ = d / 0.4887

These equations connect motor rotation angle with ideal linear wheel travel.

## 9. Reverse Maneuver Analysis

### 0.5 rotations = 180°

### d = (180 / 360) · 175.93 ≈ 87.97 mm

Ideal wheel-based displacement is approximately 87.97 mm. Actual displacement can differ because of tire slip, friction, deformation, drivetrain losses, and surface conditions.

## 10. Motor Torque

The robot uses LEGO EV3 Medium Motors. Reference running torque: 8 N·cm = 0.08 N·m. Stall torque: 12 N·cm = 0.12 N·m; stall torque represents a blocked-rotor condition rather than normal driving.

### τ = F · r

Wheel radius: r = 56/2 = 28 mm = 0.028 m.

### F = τ / r = 0.08 / 0.028 ≈ 2.86 N

This is an ideal tangential-force estimate. Actual tractive force depends on drivetrain efficiency, gearing, friction, load, and wheel slip.

## 11. Steering Geometry

Wheelbase L = 24.0 cm; track width W = 18.0 cm. The geometry is consistent with an Ackermann-type turning model.
δ

### internal = atan( L / ((L / tan(α)) − W/2) )

δ

### external = atan( L / ((L / tan(α)) + W/2) )

The inner and outer wheels follow different turning radii.

## 12. Diagonal Ultrasonic Geometry

Ywall = Ddiagonal · sin(45°) ≈ 0.7071Ddiagonal

Xforward = Ddiagonal · cos(45°) ≈ 0.7071Ddiagonal

The diagonal measurement is decomposed into lateral and forward components.

## 13. Engineering Decisions

- Use four ultrasonic sensors with two 90° and two 45° orientations.
- Use sensor differences to create the control error.
- Use the +100 calibration/control offset in the programmed ERROR equation.
- Use PID to transform ERROR into steering correction.
- Keep VEL as a numerical command with the programmed +40 / +50 offset.
- Give the front-obstacle safety routine priority.
- Base kinematic calculations on the robot's actual wheel dimensions.
- Avoid unsupported numerical assumptions.

## 14. Testing & Validation

The control system is validated through iterative testing on the real track. Sensor behavior, ERROR response, PID gains, VEL values, obstacle response, and steering behavior are evaluated and adjusted from observed robot performance.

## 15. Future Improvements

- Add stronger sensor filtering while preserving the existing control equation.
- Evaluate adaptive PID parameters for different track sections.
- Optimize programmed VEL values for stability and speed.
- Add data logging for ERROR, PID output, VEL, and sensor readings.
- Measure drivetrain torque and efficiency experimentally.
- Model slip and friction compensation.
- Compare parameter sets using repeatable track tests.

## 16. Reference Values

Parameter | Value | Meaning
Wheelbase L | 24.0 cm | Distance between front/rear axle lines
Track width W | 18.0 cm | Lateral distance between wheel paths
Wheel diameter D | 56.0 mm | Drive-wheel diameter
Wheel circumference C | 175.93 mm | πD
Motor resolution | 1° | EV3 Medium Motor rotation sensor
Linear distance / degree | 0.4887 mm/° | 175.93 / 360
Front critical distance | 25 cm | Safety threshold: ARD < 25 cm
Reverse command | 0.5 rotations | Ideal displacement ≈ 87.97 mm
Running torque | 0.08 N·m | Reference operating torque
Stall torque | 0.12 N·m | Blocked-rotor reference
Ideal wheel tangential force | ≈ 2.86 N | 0.08 / 0.028
ERROR offset | +100 | Calibration/control offset
VEL command | VEL_base + 40 / +50 | Programmed numerical speed command

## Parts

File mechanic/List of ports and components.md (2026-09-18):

# Ports and Components

## Vehicle

| Parameter | Value |
|:---|---:|
| Mass | **861 g** |
| Dimensions | 24 × 23 × 18 cm |
| Wheel diameter | 56.0 mm |
| Wheel circumference | 175.93 mm |
| Linear travel per motor degree | 0.4887 mm |

See [`docs/Control_Model.md`](../docs/Control_Model.md) for what these
numbers imply about traction, acceleration and steering geometry.

> [!NOTE]
> Every port assignment below was read off the robot with
> `python3 check_hw.py puertos`, which prints what ev3dev actually
> detects on each port. If the wiring changes, re-run that command rather
> than editing this file from memory.

## Motor ports

| Port | Device | Driver reported by ev3dev |
|:---|:---|:---|
| **A** | **Steering** motor | `lego-ev3-m-motor` |
| **B** | **Drive** motor | `lego-ev3-m-motor` |
| **C** | Free | — |
| **D** | Power feed for the Arduino Nano | driven as `dc-motor` |

Both motors are **medium** motors. Port D is not driving a motor: it is
used as a current source for the Nano, held at 100 % duty cycle so the
output is continuous rather than switched. Below 100 % the EV3 output is
a square wave, which a voltage regulator handles badly.

## Sensor ports

| Port | Device | How ev3dev sees it |
|:---|:---|:---|
| **1** | Free | — |
| **2** | mindsensors AbsoluteIMU (gyroscope) | `ms-absolute-imu` on `ev3-ports:in2:i2c17` |
| **3** | HuskyLens camera, via the OFDL UART adapter | `ev3-uart-84` |
| **4** | Free | — |

## USB

| Connection | Device | Appears as |
|:---|:---|:---|
| Brick USB port | Arduino Nano, five ultrasonic sensors | `/dev/ttyUSB0` |

The Nano used to sit on sensor port 4 over I²C. It was moved to USB
because the I²C on the EV3 sensor ports is not hardware: the brick
bit-bangs it in software and it runs at a few kHz. Over USB at 115200
baud there is bandwidth to spare, and it frees a sensor port.

## Electronics

* 1 LEGO EV3 Brick
* 1 Arduino Nano — reads the five ultrasonic sensors and streams them
  over USB
* 5 HC-SR04 ultrasonic sensors
* 1 HuskyLens camera with the OFDL adapter. The adapter carries its own
  microcontroller, which translates the camera's output into the LEGO
  UART protocol; it is not programmed by the team
* 1 custom PCB for sensor routing and power distribution
* 1 5 V voltage converter
* 2 LEGO EV3 medium motors
* Dupont jumper wires and LEGO EV3 cables

## Mechanical

* LEGO EV3 parts
* 3D-printed ultrasonic sensor mounts:
  * 2 mounts holding 4 sensors each
  * 1 mount holding a single sensor

## Ultrasonic sensor pins on the Nano

Sensor numbering matches the order they appear in the serial frame.

| Sensor | Trig | Echo | Position on the robot |
|:---:|:---:|:---:|:---|
| 1 | 11 | 12 | Left, 90 degrees |
| 2 | 9 | 10 | Left, 25 degrees |
| 3 | 7 | 8 | Front |
| 4 | 5 | 6 | Right, 25 degrees |
| 5 | 3 | 4 | Right, 90 degrees |

The mapping between frame index and physical position was measured with
`python3 check_hw.py mapear`, which covers one sensor at a time and
reports which index changes. It is recorded in `Src/ev3dev/wro/config.py`
as `IDX_IZQ`, `IDX_FRONTAL` and `IDX_DER`.

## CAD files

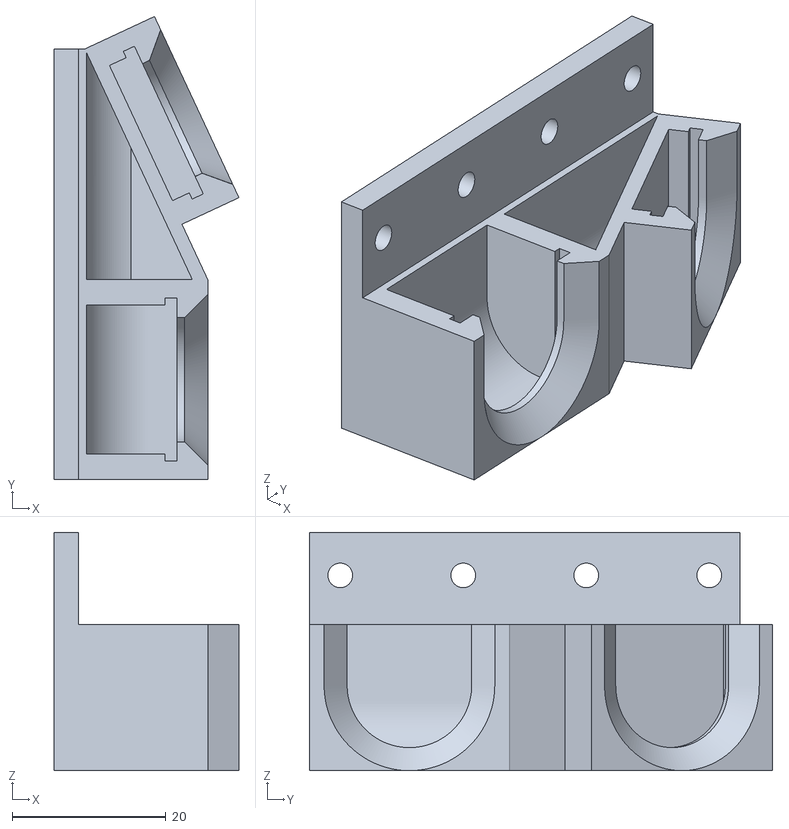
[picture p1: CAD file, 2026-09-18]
mechanic/PORTA ULTRA DOBLE (1).stl
24.1 x 60.2 x 31.0

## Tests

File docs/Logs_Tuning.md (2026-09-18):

## 📊 Iterative PID Controller Tuning Log

The closed-loop controller was tuned iteratively on the official track using a systematic trial-and-error approach. The objective was to achieve an optimal balance between damping on the straight sections and steering responsiveness in the corners.

| **Iteration** | **$K_p$** | **$K_i$** | **$K_d$** | **Speed** | **Observed Behavior / Trajectory Analysis** | **Result** |
| :---: | :---: | :---: | :---: | :---: | :--- | :---: |
| **Test 1**  | 1.80 | 0.00 | 0.00 | Low (30%) | **Critical oscillation.** The robot enters a severe overcorrection loop on the straight section, resulting in continuous zigzagging until it collides with the wall. | ❌ Rejected |
| **Test 2**  | 1.00 | 0.00 | 0.00 | Low (30%) | Oscillation is reduced on the straight section; however, the Ackermann steering response is too slow when entering tight corners, causing the robot to deviate from the intended trajectory. | ❌ Unstable |
| **Test 3**  | 0.70 | 0.00 | 0.00 |  Medium (35%) | Acceptable centering on the straight sections at low speed. However, as chassis inertia increases, the robot exhibits understeer, resulting in insufficient steering response in the corners. |  ❌ Further Tuning Required |
| **Test 4**  | 0.70 | 0.00 | 0.20 |  Medium (35%) | A predictive braking effect becomes noticeable. The robot rapidly reduces lateral oscillations after exiting a corner. | ⚠️ Promising |
| **Test 5**  | 0.90 | 0.00 | 0.40 |  Medium (35%) | Excellent response. The 45° sensor fusion anticipates the upcoming curve effectively, allowing the robot to remain near the center of the track with minimal oscillation. | ⚠️ Stable |
| **Test 6**  | 0.90 |  0.00001  | 0.20 |  Medium (30%) | The accumulated error rapidly saturates the steering actuator due to track imperfections. As a result, the robot deviates uncontrollably from the intended trajectory. | ❌ Saturation |
| **Test 7**  | 0.95 |  0.00001  | 0.35 | High (45%)  | After regulating $K_i$, increasing the base speed introduces a slight correction delay during the straight-to-corner transition due to increased inertia. A stronger derivative action is therefore required. | ⚠️ Further Tuning Required |
| **Test 8**  | 1.10 |  0.00001  | 0.30 | High (45%)  | Increasing $K_p$ provides the steering aggressiveness required to enter tight corners at high speed, while the derivative term effectively compensates for the resulting kinematic effects. | ✅ Accepted |
| **Test 9**  | 0.80 |  0.00001  | 0.25 | Maximum (60%) | When operating near the physical limits of the motors, the chassis begins to drift due to rear-tire slip. Consequently, the ideal kinematic model becomes less accurate because of tire friction and dynamic effects. | ❌ Physical Limit |
|  **Test 10**  | 0.80 |  0.00001  | 0.20 | Maximum (60%) | The robot consistently completes all three laps while maintaining relatively clean trajectories and stable lap times. |  ✅ **Semi-Ideal Baseline** |

### 💡 Analysis of the Integral Term ($K_i$)

Starting with **Test 6**, it was determined that the integral gain ($K_i$) should be maintained at **0.00001**. This decision was primarily driven by the occurrence of **integral windup**. Because the corners generate a sustained tracking error for short periods of time, the integral term accumulates error and produces unnecessary additional steering torque. This causes the Ackermann steering mechanism to deviate from its intended geometric response, ultimately compromising the overall stability of the prototype.

Therefore, a low but non-zero integral gain of **$K_i = 0.00001$** was selected as the final value, providing limited compensation for accumulated tracking error while minimizing the risk of excessive integral accumulation and actuator saturation.

## 📑 Notes
However, the tuning process did not end with these ten iterations. We continued applying the same systematic methodology, performing additional tuning rounds to further refine the controller's performance. The ten tests presented above represent only a representative portion of the tuning process; in total, we conducted approximately **40–50 additional iterations**, continuously adjusting the PID gains and evaluating the robot's trajectory, stability, and performance at different speeds.

This extended iterative process allowed us to progressively identify the limitations of the controller and converge toward a more reliable set of parameters for the final implementation.

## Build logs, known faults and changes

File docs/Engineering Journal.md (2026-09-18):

## Engineering Journal
---

### 4 July 2026 – Initial Prototyping & Basic Control Code
We developed the first version of our steering and traction control system for the Open Challenge. The software implemented a PD (Proportional–Derivative) controller using two ultrasonic sensors to keep the robot centered inside the lane. We selected a PD controller because it provides a fast and stable response while avoiding the unnecessary complexity of an integral term for this stage of development.

---

### 8 July 2026 – PCB Manufacturing
To reduce wiring complexity, eliminate loose connections, and improve signal integrity across all sensor channels, we designed a custom PCB for sensor routing and sent it to a manufacturer in China for production.

---

### 10 July 2026 – Hardware Integration
The custom PCB arrived and was successfully assembled. Initial bench tests confirmed reliable power distribution and clean communication signals for the sensor array, significantly improving the electrical reliability and organization of the robot.
---

### 13 July 2026 – Advanced Control Software & FSM Implementation

We developed the first beta version of our Finite State Machine (FSM) in MicroPython. The system switches between different driving states, including straight-line PD centering and an asymmetrical open-loop curve-following mode. We implemented an FSM because we believed the robot required decision-making capabilities beyond a traditional feedback controller, allowing it to adapt its behavior according to different driving situations.
---

### 21 July 2026 – Hardware Delay
We continued testing with the beta version of our software while waiting for additional cables that had been ordered and were scheduled to arrive on 22 July 2026.
---

## 21 July 2026 – I²C Communication Development
We programmed the communication system for our custom PCB using the I²C protocol, allowing multiple ultrasonic sensors to communicate efficiently through a simplified wiring architecture.

### 27 July 2026 – Pre-final Hardware Integration
Today, we integrated the sensor multiplexer into the robot, allowing us to remove almost all cables connected to the numbered EV3 input ports. As a result, only one of the original four sensor ports is now required.

We also installed custom 3D-printed mounts for the ultrasonic sensors, improving their alignment, rigidity, and overall integration with the chassis.

Finally, due to development time constraints and the need for rapid testing, we decided to migrate the control software back to EV3-G (EV3 Blocks). To maintain transparency and reproducibility, we will include both the original source code and a pseudocode version in the Source Code (src) section of our repository.
---
### **28 July 2026 – Final Hardware Integration and *The Robot***

Today, we completed the full assembly of our robot and successfully integrated the custom PCB, ultrasonic sensors, and all major hardware components. With its larger structure, it now looks more like an SUV than a regular car.

At first, we were concerned about the robot's dimensions because the competition rules require it to stay within **30 × 30 × 30 cm**. Fortunately, the final measurements are approximately **24 × 23 × 18 cm**, well within the allowed limits.

Another important concern was the robot's center of gravity. To improve stability, we placed the EV3 Brick at the rear of the chassis while positioning the drive motors near the center, resulting in a more balanced weight distribution.

On the software side, we have already developed a significant portion of the codebase. However, the most important milestone still lies ahead: making everything work together reliably. We believe that, with the hardware now complete, software development and testing will be more straightforward. We expect the next stage of development to focus primarily on software integration, reliability, and testing.

---
###  **24 August 2026** – I²C Communication Problems and Hardware Bottleneck

After several weeks of development, I²C became a major problem for us because the Arduino Nano we were using was defective. The board was missing its factory bootloader, and for some reason, we were unable to reinstall it. We tried everything we knew, including several alternative workarounds, but after four weeks, nothing worked.

The solution was to purchase a new Nano. We confirmed that the software itself was working by testing it with a borrowed Nano that did not have the same issue. This allowed us to conclude that the original board was faulty rather than the software being the source of the problem.

Now, we are waiting for the new Nano so we can continue testing the programs and resume the I²C integration.

---

## **28 / August / 2026**
We began testing the robot and tuning the control system on the track. It appears we have found the optimal values; however, we will continue testing. Having successfully completed the Open Challenge, we are now shifting our focus to the Obstacle Challenge.

---

## **06 / September/ 2026**
### **6 September 2026 – IMU Integration for the Obstacle Challenge**

We decided to integrate a LEGO IMU sensor into our robot because our color sensor, which uses an HSV-based configuration, was experiencing noticeable delays, possibly due to its age. These delays could affect the reliability of the robot during the Obstacle Challenge, particularly when precise movement detection is required.

To address this issue, we integrated the IMU into our control system and created a custom My Block to handle its operation. The logic is relatively simple: the IMU monitors the robot's rotation, and once it detects three complete 360-degree rotations, it sends a command to stop the motors and terminate the program.

We are currently planning to use this system as part of our strategy for the Obstacle Challenge. Further testing will be required to determine the accuracy and reliability of the IMU under actual competition conditions.

---

### **12 September 2026 – Migration to ev3dev, and the Nano moved to USB**

We migrated the control software to Python running on **ev3dev**, a Debian Linux distribution for the EV3 brick, and this is now the version we will compete with.

The reason was not novelty. Writing the controller as blocks meant approximating it: the range mapping and the dead band had to be built from whatever blocks were available, and the reasoning behind each constant lived in our heads rather than in the program. In Python each piece is written literally, and — more importantly for us — **every tuning value can carry the measurement it came from** in a comment right next to it.

We also moved the Arduino Nano off the I²C sensor port and onto the brick's **USB port**. We had assumed the I²C was slow because of our wiring. It is not: the EV3 has no I²C hardware at all, it bit-bangs the protocol in software and runs at a few kHz. Over USB at 115200 baud the Nano sends about 110 lines per second, far more than the control loop consumes, and it frees a sensor port as a bonus.

The new firmware sends one line after **every** sensor rather than after every complete sweep, so the EV3 always has the freshest possible reading. The EV3 side discards the stale lines and keeps only the most recent complete one.

---

### **13 September 2026 – The steering was not dead, it was being interrupted**

The robot had a symptom we could not explain: the steering barely turned, no matter how much we raised the gain. We had pushed the proportional gain as high as 10 chasing it.

We first measured the mechanism itself, by pushing the steering against both mechanical stops and recording where it ended up. Two findings came out of that:

**The stop is not where the motor stops moving.** At 40 % duty the steering advances 28 degrees and jams halfway; it takes 100 % to actually reach the stop. Our earlier routine accepted that first stall as the stop, which measured 26 degrees of travel instead of 111 and put the centre almost 50 degrees off.

**Forced travel and free travel are different numbers.** Pushed at full power the mechanism gives 153 degrees; at minimum power it gives 119. Those 34 degrees of difference are the mechanism flexing against the stops, not steering we can use. We now derive the steering limit from the **free** travel with a 15 % margin.

But the real cause was in the software. The steering command was being re-issued on **every** iteration of the control loop, about thirty times a second. That command is persistent — the motor keeps driving to the commanded position on its own — so re-sending it simply restarted the EV3's position controller every 30 ms. The motor never finished its ramp. It advanced a few degrees per loop and never reached the angle we asked for.

What gave it away was that the drive train already had a guard against exactly this, with a comment explaining why. The steering had been written without it.

---

### **13 September 2026 – A dead ultrasonic sensor, and what it had been hiding**

While reading the sensor frame live we noticed the validity mask never showed all five sensors valid. One channel reported the out-of-range sentinel on **every single frame**.

That sensor is one of the two on the right side. Because it never answered, the filter substituted the maximum useful distance for it permanently, which made the right side appear far away at all times. The centring error sat at a constant **+62**, and with our gain the steering was pinned at full right lock for the entire run, regardless of where the walls actually were.

This explained something embarrassing in hindsight: **the gain of 10 we had been running was compensating for a broken sensor.** With the sensor repaired, the real operating error turned out to be between 5 and 9, and a gain of 10 saturated the steering permanently. We brought it back down.

The lesson we are taking from this is about diagnostics rather than about the sensor. Each run now reports how many readings each sensor needed substituted. A sensor failing a quarter of the time is a hardware fault, and no amount of gain tuning compensates for one.

---

### **13 September 2026 – Two microSD cards lost**

We lost two microSD cards in one session. The first became permanently write-protected: the card's own controller had locked itself read-only, which is what SD cards do when their flash wears out or a write is interrupted. It could not be recovered.

The cause was almost certainly us. We had been switching the robot off by disconnecting the battery instead of shutting down properly, and the battery had been running low enough to brown out under motor load. Both of those interrupt writes.

We now shut down properly, and we have started watching the battery voltage. That turned out to matter for more than the card: the EV3's motor output scales with battery voltage, and two identical speed tests run minutes apart gave **98 % and then 88 %** of the commanded speed as the battery sagged. Tuning done on a half-charged battery does not reproduce on a full one.

---

### **14 September 2026 – Making the camera usable**

Three separate problems had to be solved before the camera could steer reliably.

**The adapter's documentation is wrong about its own data.** Its README lists six values in the order `State, ID, X, Y, W, H`. It actually returns **eight** values, ordered `X, Y, W, H, ID, State`. We confirmed it by watching index 5 alternate between 1 and 7 — exactly the codes for "object detected" and "sees none" — with every other value dropping to zero whenever it read 7.

**Reading it the obvious way was too slow.** Eight separate reads took 49 ms, enough to hold the entire control loop down to 20 Hz. Reading the raw 32-byte block in a single call takes 5 ms, and has the side benefit that values from two different frames can never be mixed.

**The camera flickers, and the adapter switches between blocks.** A single lost frame used to hand control straight back to wall following, which at that instant saw a large error and slammed the steering to full lock — we measured it going from +1.9° to +50.6° and back inside 300 ms with the block in view the whole time. Separately, with two pillars visible the adapter does not keep reporting the same one, so the robot received commands for opposite sides on consecutive loops.

We first tried to fix both with one mechanism: holding the last good command for longer. That was wrong, and the measurement showed it clearly. Stretching the window from 0.1 s to 0.3 s **tripled** how often we were acting on held data, from 12 % of loops to 31 %, while the block switching continued exactly as before. The adapter stays on the other block for longer than any window we could justify.

So we split them. The hold window went back to 0.15 s, which is what it is good at — covering the one-to-three-loop dropouts we actually measured. For the switching we used the **width** of the bounding box: the pillars are all identical, so the wider one is the closer one, and the closest is the one that has to be avoided. Control only moves to a different block when the new one looks clearly wider.

---

### **14 September 2026 – Corners that were not corners**

Running a full lap of the obstacle challenge, the robot counted four corners when it had only turned three.

The cause is that our corner detector integrates the gyroscope, and **it cannot tell a track corner from an avoidance manoeuvre.** When the camera sends the steering to full lock to get around a pillar, the robot genuinely turns, and it genuinely accumulates the 87 degrees we use as the corner threshold.

The spacing gave it away: two corners arrived **1.1 seconds apart**, where the real ones had been coming every 6 seconds.

In a race this is fatal rather than cosmetic. Every false corner brings the target of twelve closer, and the robot would brake in the middle of the track convinced it had completed three laps.

We now reject any corner arriving less than 1.5 seconds after the previous one. The accumulated angle is still reset when we reject one, because that turn physically happened and carrying it forward would trigger the next corner early. Each run reports how many were rejected, so we can tell the difference between the filter working and the filter hiding something.

---

### **14 September 2026 – Documentation**

We brought the repository in line with the robot that actually competes. The ev3dev control software, the current Nano firmware and the technical notes are now in `Src/` and `docs/`, and the port list has been corrected against what the brick actually reports rather than what we remembered wiring.

Doing this exposed how far our documentation had drifted from our hardware. The port list had the two motors swapped and the gyroscope and camera on each other's ports. None of it had caused a problem, because the code knew the truth and only the document was wrong — which is exactly why nobody noticed.

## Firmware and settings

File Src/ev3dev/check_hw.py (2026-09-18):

#!/usr/bin/env python3
"""Hardware diagnostics, to run before any race program.

This exists because a handful of values cannot be decided at a desk.
They depend on how this particular robot is wired and assembled, and
guessing them wrong produces failures that look like software bugs:

  1. which frame index belongs to which ultrasonic sensor;
  2. what IMU_ESCALA is, and with which sign;
  3. which way the steering turns for a positive angle;
  4. how far the steering actually travels, stop to stop;
  5. the reduction between the drive motor and the rear wheel, which is
     what makes a speed in cm/s mean anything.

Every command here either only reads, or says plainly that it moves the
robot.

Usage:
    python3 check_hw.py puertos     what ev3dev sees on each port
    python3 check_hw.py serie       raw lines from the Nano over USB
    python3 check_hw.py ultra       decoded ultrasonic frame, live
    python3 check_hw.py mapear      which index is which sensor
    python3 check_hw.py husky       raw HuskyLens values
    python3 check_hw.py imu         raw gyroscope reading
    python3 check_hw.py escala      compute IMU_ESCALA
    python3 check_hw.py lazo        full control loop, motors off
    python3 check_hw.py alimentacion power port D for the Nano
    python3 check_hw.py motores     confirm which motor is which
    python3 check_hw.py topes       measure the steering travel
    python3 check_hw.py volante     steering direction
    python3 check_hw.py reduccion   motor-to-wheel reduction, for cm/s
    python3 check_hw.py parar       stop motors and cut power
"""

import glob
import math
import os
import sys
import time

sys.path.insert(0, os.path.dirname(os.path.abspath(__file__)))

from wro import config, ports


def parar():
    """Shut everything down: drive, steering and the Nano's power.

    For when something was left running because a program died without
    reaching its `finally` -- terminal closed, ssh dropped. Safe to run
    at any time.

    Worth knowing: a program killed mid-run can leave port D powering the
    Nano indefinitely, which quietly drains the battery.
    """
    for ruta in sorted(glob.glob('/sys/class/tacho-motor/motor*')):
        with open(os.path.join(ruta, 'address')) as f:
            direccion = f.read().strip()
        with open(os.path.join(ruta, 'command'), 'w') as f:
            f.write('stop')
        print('%-16s detenido' % direccion)

    for ruta in sorted(glob.glob('/sys/class/dc-motor/motor*')):
        with open(os.path.join(ruta, 'address')) as f:
            direccion = f.read().strip()
        with open(os.path.join(ruta, 'command'), 'w') as f:
            f.write('stop')
        print('%-16s sin corriente' % direccion)

    print('todo apagado')


def puertos():
    print('--- lego-port ---')
    for ruta in sorted(glob.glob('/sys/class/lego-port/port*')):
        try:
            with open(os.path.join(ruta, 'address')) as f:
                direccion = f.read().strip()
            with open(os.path.join(ruta, 'mode')) as f:
                modo = f.read().strip()
            print('%-28s %-14s %s' % (direccion, modo, os.path.basename(ruta)))
        except IOError:
            pass

    print('--- lego-sensor ---')
    for ruta in sorted(glob.glob('/sys/class/lego-sensor/sensor*')):
        with open(os.path.join(ruta, 'address')) as f:
            direccion = f.read().strip()
        with open(os.path.join(ruta, 'driver_name')) as f:
            driver = f.read().strip()
        with open(os.path.join(ruta, 'modes')) as f:
            modos = f.read().strip()
        print('%-28s %-20s %s' % (direccion, driver, modos))

    print('--- buses I2C ---')
    for ruta in sorted(glob.glob('/dev/i2c-*')):
        print(ruta)

    print('--- serie USB ---')
    encontrados = sorted(glob.glob('/dev/ttyUSB*') + glob.glob('/dev/ttyACM*'))
    if encontrados:
        for ruta in encontrados:
            print(ruta)
    else:
        print('ninguno; revise el cable del Nano y dmesg | tail')

    print('--- motores ---')
    for ruta in sorted(glob.glob('/sys/class/tacho-motor/motor*')):
        with open(os.path.join(ruta, 'address')) as f:
            direccion = f.read().strip()
        with open(os.path.join(ruta, 'driver_name')) as f:
            driver = f.read().strip()
        print('%-28s %s' % (direccion, driver))


def serie():
    """Raw lines from the Nano, exactly as they arrive over USB.

    Separates a cabling problem from a format problem. You should see
    lines like: U 34 51 125 47 30 27 91 12
    """
    import serial
    from wro.ultrasonics import HubSerial

    puerto = config.ARD_PUERTO_SERIE or HubSerial.buscar_puerto()
    print('abriendo %s a %d baudios' % (puerto, config.ARD_BAUDIOS))
    con = serial.Serial(puerto, config.ARD_BAUDIOS, timeout=1)
    time.sleep(config.ARD_ESPERA_ARRANQUE)
    con.reset_input_buffer()
    try:
        while True:
            linea = con.readline()
            if linea:
                print(linea.decode('ascii', 'replace').strip())
    except KeyboardInterrupt:
        con.close()


def husky():
    """Raw HuskyLens values through the OFDL adapter.

    Settles three things:

      - which mode to put in HUSKY_MODO;
      - what range X and Y actually arrive in, to set HUSKY_CENTRO_X/_Y
        and to check whether the axes need inverting;
      - which ID belongs to which colour, for HUSKY_ID_VERDE and
        HUSKY_ID_ROJO.

    Hold one block of each colour in front of the camera and note the ID.
    This is the only way to settle it: a swapped colour ID produces
    exactly the same symptom as reversed target signs.

    Shows the raw angle, without the hold-over filter, so a flickering
    camera is visible rather than smoothed away.
    """
    from wro.husky import HuskyLens

    cam = HuskyLens()
    print('driver   : %s' % cam.sensor.driver_name)
    print('modos    : %s' % cam.sensor.modes)
    print('modo     : %s' % cam.sensor.mode)
    print('n valores: %s' % cam.sensor.num_values)
    print()
    print('targets: VERDE %+d   ROJO %+d   (wro/config.py)'
          % (config.HUSKY_TARGET_VERDE, config.HUSKY_TARGET_ROJO))
    print()
    print('color     X  target  error  volante  lado')
    try:
        while True:
            if not cam.actualizar():
                print('%-8s  %s' % ('-', cam.diagnostico()))
            else:
                target = cam.target()
                if target is None:
                    print('%-8s ID %d no configurado como verde ni rojo'
                          % (cam.color, cam.id))
                else:
                    angulo = cam.angulo_esquive()
                    print('%-6s %+4.0f   %+4d   %+5.0f   %+6.1f  %s'
                          % (cam.color, cam.x, target, cam.x - target, angulo,
                             'DERECHA' if angulo > 0 else 'IZQUIERDA'))
            time.sleep(0.3)
    except KeyboardInterrupt:
        pass


def ultra():
    """Show the decoded frame live.

    Cover one sensor at a time with your hand and note which column
    changes. That fills in IDX_IZQ, IDX_FRONTAL and IDX_DER in config.py.

    Both the raw and the filtered columns are shown, so it is visible
    when the filter is substituting a reading rather than reporting one.
    """
    from wro.ultrasonics import crear_hub

    hub = crear_hub()
    print('crudo                | filtrado             | valido trama  error')
    try:
        while True:
            ok = hub.actualizar()
            print('%s | %s | %s  %-6d %6.1f %s'
                  % (' '.join('%4d' % d for d in hub.distancias),
                     ' '.join('%4d' % d for d in hub.utiles),
                     format(hub.validez, '05b'), hub.trama,
                     hub.error_crudo(), '' if ok else 'CHECKSUM MALO'))
            time.sleep(0.2)
    except KeyboardInterrupt:
        print('tramas malas: %d de %d' % (hub.tramas_malas, hub.tramas_leidas))
        print('sustituciones por sensor: %s' % hub.sin_eco)
    finally:
        # Without this, a Ctrl-C leaves port D powering the Nano forever
        # and the battery drains.
        hub.cerrar()


def mapear():
    """Work out which frame index belongs to which ultrasonic sensor.

    Takes a baseline with everything clear, then asks for one sensor to
    be covered at a time. Prints the resulting IDX_ lines ready to paste
    into wro/config.py.
    """
    from wro.ultrasonics import crear_hub

    hub = crear_hub()
    try:
        _mapear(hub)
    finally:
        # Without this, quitting halfway leaves port D powering the Nano.
        hub.cerrar()


def _mapear(hub):
    CERCA = 30           # cm: below this a sensor counts as covered

    def mediana(valores):
        ordenados = sorted(valores)
        return ordenados[len(ordenados) // 2]

    def medir(segundos=2.0):
        """Median per sensor, not mean.

        These sensors emit an occasional 125 (out of range), and one
        such value shifts a mean by 20 cm. The median ignores them.
        """
        muestras = [[] for _ in range(5)]
        limite = time.time() + segundos
        while time.time() < limite:
            if hub.actualizar():
                for i in range(5):
                    muestras[i].append(hub.utiles[i])
            time.sleep(0.03)
        if not muestras[0]:
            raise IOError('no llego ninguna trama valida del Nano')
        return [mediana(m) for m in muestras]

    print('Deje los cinco ultrasonicos despejados, sin nada cerca.')
    input('Enter para tomar la linea base... ')
    base = medir()
    print('base: %s' % ' '.join('%5.0f' % v for v in base))
    print()

    posiciones = [
        ('izquierda 90', 'IZQ'),
        ('izquierda 25', 'IZQ'),
        ('frontal', 'FRONTAL'),
        ('derecha 25', 'DER'),
        ('derecha 90', 'DER'),
    ]

    hallados = []
    for nombre, grupo in posiciones:
        while True:
            input('Mano a unos 10 cm del ultrasonico %s, sostengala, Enter... '
                  % nombre)
            actual = medir()

            # A covered sensor has to satisfy TWO conditions: read close
            # in absolute terms, AND have dropped relative to its own
            # baseline. "Whichever changed most" on its own gets swamped
            # by noise, which on these sensors reaches 35 cm with nobody
            # touching them.
            usados = [h[0] for h in hallados]
            puntajes = []
            for i in range(5):
                if i in usados or actual[i] > CERCA:
                    puntajes.append(None)
                else:
                    puntajes.append(base[i] - actual[i])

            print('   tapado: %s'
                  % ' '.join('%5.0f' % v for v in actual))
            print('   bajada: %s'
                  % ' '.join('    -' if p is None else '%5.0f' % p
                             for p in puntajes))

            validos = [(p, i) for i, p in enumerate(puntajes)
                       if p is not None and p > 3]
            if validos:
                indice = max(validos)[1]
                print('   -> indice %d (sensor %d)' % (indice, indice + 1))
                print()
                hallados.append((indice, grupo))
                break

            print('   Ningun sensor libre quedo por debajo de %d cm con una'
                  % CERCA)
            print('   bajada clara. Acerque mas la mano y repita.')
            print()

    izq = [str(i) for i, g in hallados if g == 'IZQ']
    der = [str(i) for i, g in hallados if g == 'DER']
    frontal = [str(i) for i, g in hallados if g == 'FRONTAL']

    print('Pegue esto en wro/config.py:')
    print()
    print('IDX_IZQ = (%s)' % ', '.join(izq))
    print('IDX_FRONTAL = %s' % (frontal[0] if frontal else '?'))
    print('IDX_DER = (%s)' % ', '.join(der))


def imu():
    """Raw gyroscope reading, with no scaling and no offset applied."""
    from wro.imu import Giroscopio

    giro = Giroscopio(escala=1.0)
    print('Dejelo quieto: la columna cruda deberia ser casi constante.')
    try:
        while True:
            crudo = giro.lector.crudo()
            print('crudo %8d' % crudo)
            time.sleep(0.1)
    except KeyboardInterrupt:
        pass


def escala():
    """Work out IMU_EJE and IMU_ESCALA in one go.

    Integrates ALL THREE gyroscope axes while the robot is turned
    through a known angle by hand. The vertical axis of this build is
    the one that accumulates a lot; the other two only pick up wobble.
    Comparing what accumulated against the real angle gives the scale,
    with its sign.

    A full turn is used rather than 90 degrees because the error of
    starting and stopping by eye then counts for four times less.

        python3 check_hw.py escala          una vuelta, 360 grados
        python3 check_hw.py escala 90       si prefieren un cuarto
    """
    import threading

    from wro.imu import Giroscopio

    objetivo = float(sys.argv[2]) if len(sys.argv) > 2 else 360.0

    giro = Giroscopio(escala=1.0)

    print('Robot quieto sobre la mesa. Calibrando el cero...')
    ceros = [0.0, 0.0, 0.0]
    MUESTRAS = 200
    for _ in range(MUESTRAS):
        lectura = giro.lector.crudo_todos()
        for i in range(3):
            ceros[i] += lectura[i] / float(MUESTRAS)
        time.sleep(0.002)
    print('cero por eje: %s' % ' '.join('%+7.2f' % c for c in ceros))
    print()

    print('Al pulsar Enter empieza a medir. Gire el robot %g grados' % objetivo)
    print('HACIA LA DERECHA, despacio y sin levantarlo, y pulse Enter otra vez.')
    input('Enter para empezar... ')

    acumulado = [0.0, 0.0, 0.0]
    picos = [0, 0, 0]
    muestras = 0
    inicio = time.time()
    ultimo = inicio

    listo = threading.Event()
    hilo = threading.Thread(target=lambda: (sys.stdin.readline(), listo.set()))
    hilo.daemon = True
    hilo.start()

    while not listo.is_set():
        lectura = giro.lector.crudo_todos()
        ahora = time.time()
        dt = ahora - ultimo
        ultimo = ahora
        for i in range(3):
            acumulado[i] += (lectura[i] - ceros[i]) * dt
            picos[i] = max(picos[i], abs(lectura[i] - ceros[i]))
        muestras += 1
        time.sleep(0.005)

    duracion = time.time() - inicio

    print()
    print('%d muestras en %.1f s  (%.0f Hz)'
          % (muestras, duracion, muestras / duracion if duracion else 0))
    print()
    print('eje   acumulado    pico crudo')
    for i in range(3):
        print(' %d   %+10.1f   %9d   %s'
              % (i, acumulado[i], picos[i], 'X Y Z'.split()[i]))
    print()

    mejor = max(range(3), key=lambda i: abs(acumulado[i]))
    segundo = sorted(range(3), key=lambda i: abs(acumulado[i]))[-2]

    if abs(acumulado[mejor]) < 1e-6:
        print('No se acumulo nada en ningun eje. El sensor no esta leyendo:')
        print('revise el cable y pruebe `python3 check_hw.py imu`.')
        return

    if abs(acumulado[mejor]) < 3 * abs(acumulado[segundo]):
        print('AVISO: el eje %d no destaca sobre el %d. Deberia acumular'
              % (mejor, segundo))
        print('mucho mas que los otros dos. Puede que haya girado poco, o')
        print('que haya inclinado el robot al girarlo. Repita mas limpio.')
        print()

    print('Pegue esto en wro/config.py:')
    print()
    print('IMU_EJE = %d' % mejor)
    print('IMU_ESCALA = %.6f' % (objetivo / acumulado[mejor]))
    print()
    print('Si la escala sale negativa, dejenla negativa: eso significa que')
    print('el sensor cuenta al reves de como esta montado, y el signo lo')
    print('corrige.')


def lazo():
    """Run the full control loop WITHOUT moving the motors.

    The dress rehearsal: reads all three sensors, computes the error,
    the steering angle and the corner count exactly as open_ard.py and
    obs_ard.py will, but sends nothing to the drive or the steering.

    Useful for two things that only show up with everything running
    together:

      - how many control loops per second actually happen, which is what
        decides whether the robot corrects in time;
      - whether the signs are consistent. Push the robot by hand towards
        a wall and check the angle comes out towards the opposite side.

    Ctrl-C to exit.
    """
    from wro.husky import HuskyLens
    from wro.imu import Giroscopio
    from wro.ultrasonics import crear_hub
    from wro.util import clamp_abs

    hub = crear_hub()
    giro = Giroscopio()

    try:
        camara = HuskyLens()
    except Exception as error:
        print('sin camara (%s); se prueba solo el seguimiento de pared'
              % error)
        camara = None

    print('Robot quieto. Calibrando el cero del giroscopio...')
    giro.calibrar(muestras=200)
    print('offset: %.2f' % giro.offset)
    print()
    print('MOTORES APAGADOS. Empuje el robot a mano.')
    print('Ctrl-C para salir.')
    print()
    print(' Hz   izq   der  error  angulo  grados esq  fuente')

    esquinas = 0
    vueltas = 0
    inicio = time.time()
    ultimo_aviso = inicio

    try:
        while True:
            arranque = time.time()

            hub.actualizar()
            angulo_imu = giro.actualizar()
            if camara is not None:
                camara.actualizar()

            if abs(angulo_imu) >= config.ANGULO_ESQUINA:
                giro.reiniciar()
                esquinas += 1

            angulo = None
            fuente = 'DIS'
            if camara is not None and camara.hay_objeto:
                angulo = camara.angulo_esquive()
                if angulo is not None:
                    fuente = 'CAM id=%d' % camara.id

            if angulo is None:
                angulo = clamp_abs(config.VOLANTE_KP * hub.error_crudo(),
                                   config.VOLANTE_LIMITE)

            vueltas += 1
            ahora = time.time()
            if ahora - ultimo_aviso >= 0.25:
                ultimo_aviso = ahora
                print('%4.0f  %4d  %4d  %+5.0f  %+6.1f  %+6.1f %3d  %s'
                      % (vueltas / (ahora - inicio),
                         sum(hub.izquierda), sum(hub.derecha),
                         hub.error_crudo(), angulo, angulo_imu,
                         esquinas, fuente))

            resto = config.PERIODO_LAZO - (time.time() - arranque)
            if resto > 0:
                time.sleep(resto)
    except KeyboardInterrupt:
        pass
    finally:
        hub.cerrar()

    duracion = time.time() - inicio
    print()
    print('%d vueltas en %.1f s = %.0f Hz'
          % (vueltas, duracion, vueltas / duracion if duracion else 0))
    print('tramas malas del Nano: %d de %d'
          % (hub.tramas_malas, hub.tramas_leidas))
    print('lecturas sin eco sustituidas, por sensor: %s' % hub.sin_eco)


def motores():
    """Confirm which motor is which, by moving one at a time.

    The movements are 15 degrees, within the usable steering travel, so
    they do not strain the stops. Even so, lift the robot or put it on a
    stand before running this.
    """
    from ev3dev2.motor import Motor

    print('--- lo que hay conectado ---')
    for ruta in sorted(glob.glob('/sys/class/tacho-motor/motor*')):
        with open(os.path.join(ruta, 'address')) as f:
            direccion = f.read().strip()
        with open(os.path.join(ruta, 'driver_name')) as f:
            driver = f.read().strip()
        print('  %-16s %s' % (direccion, driver))

    print()
    print('--- lo que dice wro/config.py ---')
    print('  PUERTO_TRACCION = %s' % config.PUERTO_TRACCION)
    print('  PUERTO_VOLANTE  = %s' % config.PUERTO_VOLANTE)
    print()
    print('Levante el robot o pongalo sobre un soporte.')

    for etiqueta, puerto in (('TRACCION', config.PUERTO_TRACCION),
                             ('VOLANTE', config.PUERTO_VOLANTE)):
        input('Enter para mover el motor de %s (%s)... ' % (etiqueta, puerto))
        motor = Motor(puerto)
        motor.stop_action = 'hold'
        inicio = motor.position
        for destino in (inicio + 15, inicio - 15, inicio):
            motor.speed_sp = 150
            motor.position_sp = destino
            motor.run_to_abs_pos()
            time.sleep(0.6)
        motor.stop(stop_action='coast')
        print('   se movio el motor de %s. Era el correcto?' % etiqueta)
        print()

    print('Si se movio el que no era, intercambie PUERTO_TRACCION y')
    print('PUERTO_VOLANTE en wro/config.py.')


def alimentacion():
    """Power port D as a current source for the Nano.

    Leaves the output at 100 %, which is continuous. Below that it would
    be a square wave, which is no use for powering electronics.
    """
    from wro.power import AlimentacionNano

    if not config.ARD_ALIMENTACION_PUERTO:
        print('ARD_ALIMENTACION_PUERTO esta en None: el Nano se alimenta')
        print('solo por USB. No hay nada que probar.')
        return

    alim = AlimentacionNano()
    print('puerto %s, ciclo de trabajo %d %%'
          % (alim.puerto, alim.duty))
    print('Mida con el multimetro entre los pines de potencia: deberia')
    print('salir la tension de la bateria, no una fraccion de ella.')
    print()
    alim.encender()
    print('encendida: %s' % alim.encendida)
    try:
        input('Enter para apagar... ')
    except (EOFError, KeyboardInterrupt):
        pass
    alim.apagar()
    print('apagada')
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

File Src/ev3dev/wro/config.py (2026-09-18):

"""Robot configuration: ports, wiring and gains.

Everything that needs adjusting at the track should live in this file.

Most values here are measured rather than chosen. Where that is the case
the comment says how it was measured and what the number means, because
a tuning value with no recorded reasoning is one nobody dares change.
"""


# Underscored so that `from wro.config import *` never exports it, and
# so it is obvious that nothing here is a tuning value.
import math as _math

# --------------------------------------------------------------------
# Ports
# --------------------------------------------------------------------

PUERTO_IMU = 'ev3-ports:in2'        # mindsensors AbsoluteIMU
PUERTO_HUSKY = 'ev3-ports:in3'      # HuskyLens via the OFDL adapter
PUERTO_ARD = 'ev3-ports:in4'        # only if the Nano runs over I2C

# Confirmed on the robot: BOTH motors are medium ones
# (lego-ev3-m-motor), and there is nothing on C or D.
PUERTO_TRACCION = 'outB'            # medium motor
PUERTO_VOLANTE = 'outA'             # medium motor

# --------------------------------------------------------------------
# Arduino Nano ultrasonic hub
# --------------------------------------------------------------------

# 'serial' -> ultrasonic_hub_serial firmware, Nano on the brick's USB port
# 'i2c'    -> ultrasonic_hub_packet firmware, Nano on a sensor port
ARD_BACKEND = 'serial'

ARD_PUERTO_SERIE = None             # None = auto-detect /dev/ttyUSB* or ttyACM*
ARD_BAUDIOS = 115200
ARD_ESPERA_ARRANQUE = 2.0           # opening the port resets the Nano

# Powering the Nano from a motor port, driven as a DC motor. Data still
# travels over USB; this is current only.
# Set to None if the Nano is powered over USB alone.
#
# The duty cycle MUST be 100: below that the EV3 output is a square wave
# rather than continuous, and the Nano's regulator would struggle.
ARD_ALIMENTACION_PUERTO = 'outD'
ARD_ALIMENTACION_DUTY = 100
ARD_ALIMENTACION_ESPERA = 1.5       # seconds before opening the serial port

ARD_DIRECCION = 0x08                # only for ARD_BACKEND = 'i2c'
ARD_FIRMWARE = 'packet'             # 'packet' or 'byte'

# Zero-based indices within the frame.
# Verified on the robot with `check_hw.py mapear`, covering one sensor at
# a time.
IDX_IZQ = (0, 1)                    # left 90 and left 25
IDX_FRONTAL = 2
IDX_DER = (3, 4)                    # right 25 and right 90

ARD_FUERA_DE_RANGO = 125            # the firmware's out-of-range sentinel

# --------------------------------------------------------------------
# Distance filtering
# --------------------------------------------------------------------
#
# When an ultrasonic sensor gets no echo, the firmware returns 125 and
# clears its validity bit. 125 is not a distance, it is a sentinel. Added
# straight into the error, a single sensor dropout makes the error jump
# by 80 cm and the steering slams to full lock. Measured with
# `check_hw.py lazo`: the error went from +5 to -82 and back to +31 in
# under a second, with the robot standing still.
#
# With the filter, a sensor that loses its echo keeps its last good
# reading for ARD_RETENCION seconds. If it is still silent after that,
# it is taken to mean "no wall nearby" and ARD_DISTANCIA_MAXIMA is used.
ARD_FILTRAR = True

# Useful distance ceiling, in cm. Beyond this a reading contributes
# nothing to staying centred between the walls and only adds noise to
# the error. The Future Engineers corridor is 1 m wide; the sensors at
# 25 degrees see somewhat further than the perpendicular ones, hence the
# margin.
ARD_DISTANCIA_MAXIMA = 100

# How long a sensor's last good reading is held when it loses its echo.
# At 44 Hz this is about 22 control loops.
ARD_RETENCION = 0.5

# Rolling median per sensor, to kill isolated spikes that get through
# with their validity bit set. 1 disables it; 3 is enough and adds no
# noticeable lag.
ARD_MEDIANA = 3

# --------------------------------------------------------------------
# IMU
# --------------------------------------------------------------------

# 'driver' -> lego-sensor with the ms-absolute-imu driver (recommended)
# 'raw'    -> direct I2C reads of the gyro registers
IMU_BACKEND = 'driver'

IMU_DIRECCION = 0x11                # 0x22 as 8-bit = 0x11 as 7-bit
IMU_DRIVER = 'ms-absolute-imu'
IMU_MODO = 'GYRO'
IMU_EJE = 2                         # 0=X, 1=Y, 2=Z

# Factor converting the raw reading into degrees per second.
#
# The ms-absolute-imu driver in GYRO mode reports units = d/s and
# decimals = 1: the raw integer comes multiplied by ten. That gives
# exactly 0.1.
#
# Confirmed by measurement: `check_hw.py escala` over one full turn gave
# 0.09795, within 2 %. The exact 0.1 is kept rather than the measured
# value, because 0.1 is exact by construction while the measurement
# carries the error of turning the robot by hand. What the test really
# settled was the axis and the sign.
#
# POSITIVE sign confirmed: turning right, Z accumulates positive.
IMU_ESCALA = 0.1
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

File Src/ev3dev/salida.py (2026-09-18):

#!/usr/bin/env python3
"""Parking exit: back out of a bay and point the robot at the gap.

Starts already parked, nose towards the wall, and gets out:

    1. forward until the front sensor reads SALIDA_FRENTE_MINIMO
    2. steering over to SALIDA_LADO, reverse SALIDA_RETROCESO_CM
    3. steering to the OTHER stop, and drive out

Phases 2 and 3 are one movement in two halves, which is why the wheels
go stop to stop between them rather than through centre. Reversing with
the wheels over one way swings the tail into the bay and the nose out of
it; driving forward with them over the other way continues that same
rotation. Straightening in between would throw away half of it.

All three repeat, SALIDA_CICLOS times. One pass is rarely enough from a
tight bay: it gains angle without gaining an exit, meets the wall again,
and needs to go round once more. Each pass adds rotation to the last,
which is what a multi-point turn is.

The count is fixed rather than a condition to stop at. Every cycle runs,
and the summary at the end says how many of them finished with the way
clear.

Phase 3 does not drive a set distance and then look. It keeps going
while the nose swings round and ends the moment the front sensor reads
open space instead of wall; its distance is only a ceiling, to stop the
robot circling in a bay too open to touch a wall and too closed to read
as clear.

The front ultrasonic is the only sensor that decides anything. It ends
phase 1, and it keeps a veto in phase 3 in case another wall turns up.
The lateral pair take no part: the side to turn towards is fixed in
config rather than read from the corridor, so the manoeuvre is the same
every time and there is one line to change if the bay is mirrored.

Phase 2 is measured on the encoder: the steering goes over, the robot
backs up SALIDA_RETROCESO_CM, and it stops. There is no rear
sensor, and there IS a wall back there.

The encoder stands in for the sensor that does not exist. Wheels that
stop turning while the motor is still being told to turn them mean the
robot is pushing against something, and the reverse is cut short rather
than spent grinding into it.

Press the brick's back button to stop the robot at any time.
"""

import os
import sys
import time

from ev3dev2.button import Button
from ev3dev2.sound import Sound

sys.path.insert(0, os.path.dirname(os.path.abspath(__file__)))

from wro import config
from wro.husky import HuskyLens
from wro.imu import Giroscopio
from wro.robot import Robot
from wro.ultrasonics import crear_hub


def esperar_boton(boton, sonido):
    print('Listo. Pulse el boton central para arrancar.')
    sonido.beep()
    while not boton.enter:
        time.sleep(0.05)
    while boton.enter:
        time.sleep(0.05)


def vueltas_recorridas(robot, partida):
    """Wheel turns since `partida`, from the drive encoder."""
    return (abs(robot.traccion.position - partida)
            / 360.0 / config.TRACCION_REDUCCION)


# The side the whole manoeuvre turns towards. Written once, by
# elegir_lado, before the first cycle; read by everything after it.
#
# A module level value rather than an argument threaded through six
# signatures, because that is what it is: one decision, taken at the
# start, constant for the rest of the run.
_LADO = None


def lado_elegido():
    """The side the manoeuvre is turning towards.

    Falls back to the configured side until elegir_lado has run, so
    anything asking early gets an answer rather than None.
    """
    return _LADO or config.SALIDA_LADO


def elegir_lado(hub):
    """Pick the exit side from the lateral sensors, once, for the run.

    More room on one side than the other is the whole test: the robot
    leaves towards the side with more of it. A tie, or a margin too
    small to trust, hands the decision back to SALIDA_LADO.

    Averaged over SALIDA_LADO_MUESTREO rather than read once. These are
    the two sensors this program otherwise keeps out of its decisions,
    precisely because they go quiet at an angle, and an average is the
    least it can take from them before betting the manoeuvre on it.
    """
    global _LADO

    if not config.SALIDA_LADO_AUTOMATICO:
        _LADO = config.SALIDA_LADO
        print('lado de salida   : %s (fijo en config)' % _LADO.upper())
        return _LADO

    izq = []
    der = []
    fin = time.time() + config.SALIDA_LADO_MUESTREO
    while time.time() < fin:
        hub.actualizar()
        izq.append(min(hub.izquierda))
        der.append(min(hub.derecha))
        time.sleep(0.02)

    media_izq = sum(izq) / float(len(izq)) if izq else 0.0
    media_der = sum(der) / float(len(der)) if der else 0.0
    diferencia = media_izq - media_der
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

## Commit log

2026-09-18 Bring across the full project from the Future-engineers repository
    Everything that was in WRO-2026-Grises-Jr-Mx-Future-engineers: the
    source for both boards, the engineering documents, the mechanical files,
    the videos and the LEGO model. The Src/ev3dev tree is the code as it
    runs on the brick, including the parking work -- salida.py,
    salida_libre.py, salida2.py and entrada.py -- which existed in neither
    repository until today.
    Nothing that was already here was thrown away. Two files would have
    collided and both were kept under a dated name instead:
    README.md -> README-abril-2026.md
    LICENSE -> LICENSE-abril-2026
    The first of those matters more than it looks: this repository's
    README.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
    [PORTA ULTRA DOBLE (1).stl]
2026-09-18 Drop the duplicate licence file
    LICENSE-abril-2026 was kept aside when the two repositories were merged,
    on the grounds that the two licence files were not byte-identical. They
    turn out to differ by nothing that matters: same MIT text, same holder,
    same year, and twenty-one bytes of CRLF line endings against LF.
    One licence, so one file.
